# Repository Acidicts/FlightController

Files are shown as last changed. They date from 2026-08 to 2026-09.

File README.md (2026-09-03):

# My Simple Flight Controller
Made by following a tutorial by @notaroomba

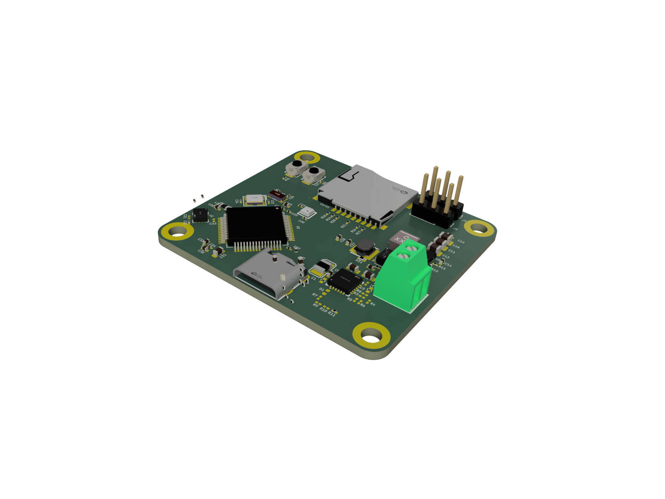
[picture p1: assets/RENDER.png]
RENDER IMG


<div style="display:inline-block">
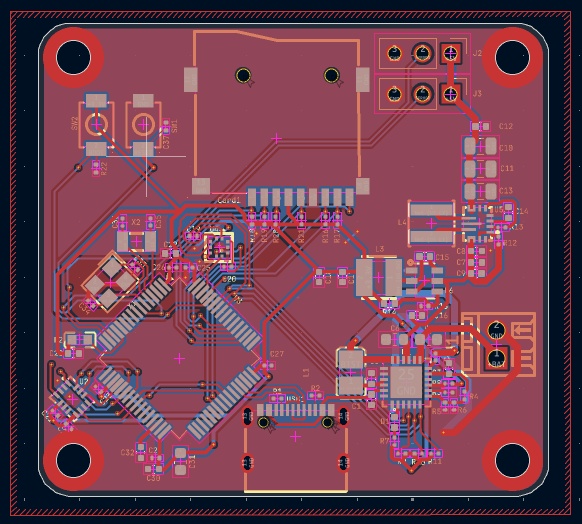
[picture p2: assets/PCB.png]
    
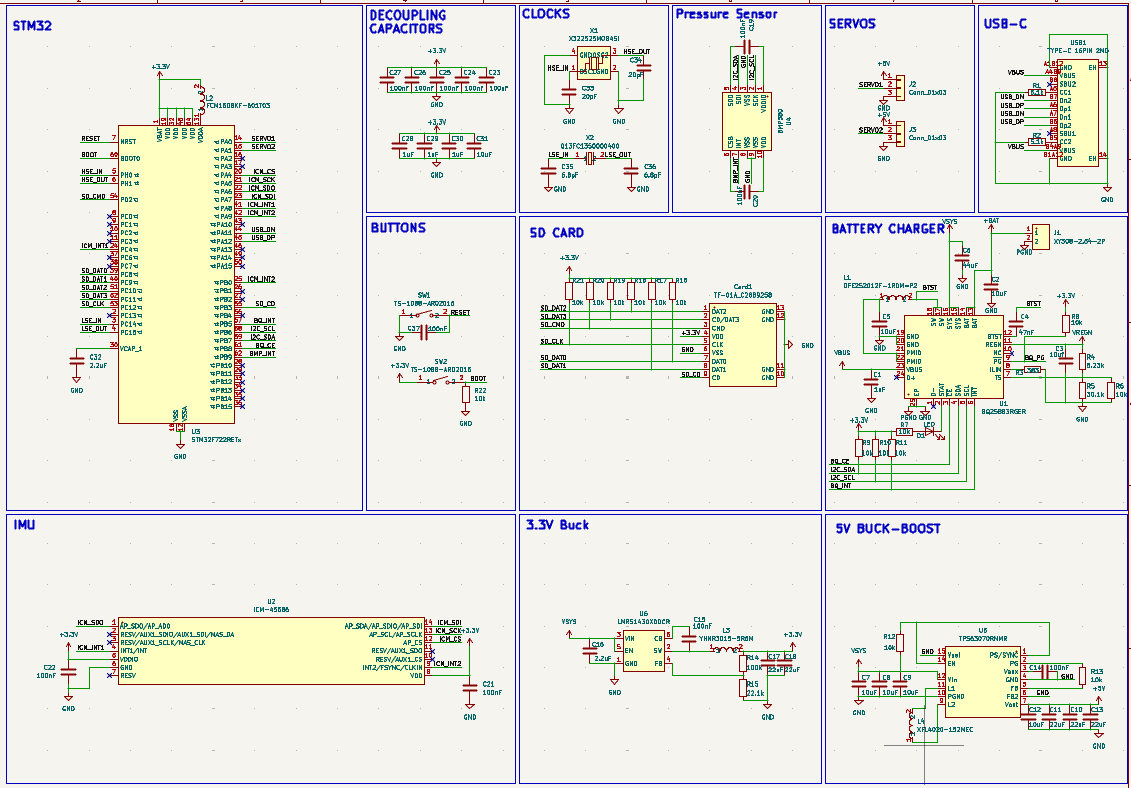
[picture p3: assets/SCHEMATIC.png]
    
</div>

## I learnt:
- That you can route sections of a pcb the bring them together to finish
- How to do ground fill in KiCAD
- That texas instruments is a good site to look on

## Features
| Name | Description | Part Name | Usage |
| --- | --- | --- | --- |
| MCU | High Speed MCU | STM32F722RET6 | This is the brains and allows management of all the other components connected to it |
| Barometer | For relative height measuring from launch altitude | BMP580 | This allows altitude tracking for each flight mission |
| IMU | Tracks movement | ICM-45686 | This allows tracking of the flight path and orientation of the craft using the 3 axis gyroscope in it |
| Battery Charger | Manages battery charging for Lithium Batteries | BQ25883RGER | This manages the battery and allows smooth discharge and charging of the battery to prevent damage to the battery and the board |
| High speed clock | Provides high-speed frequency to MCU (~25MHz) | X322525MOB4SI | This provides the main clock signal for the MCU |
| Low speed clock | Provides low-speed frequency to MCU (32.768kHz) | Q13FC13500004 | This provides a stable time base for the MCU |
| Battery Screw Terminal | For connecting battery | XY308-2.54-2P | This allows easy connection of the battery to the board (no soldering today) |
| Two servo pin headers | For connecting the servos | 2.54-1*3P | This allows easy connection of the servos to the board allowing hot swapping servos or cables |

## Getting Started
Click [here](GETTING_STARTED.md)

## BOM
[BOM](./BOM.csv)

[PCB BOM](./PCB_BOM.csv)

[PCB BOM UNSELECTED](./PCB_BOM_UNSELECTED.csv) - Most due to not being in stock or I couldn't find them on lcsc

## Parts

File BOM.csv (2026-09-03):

What | Quantity | Cost(USD) | Source
PCB | 5 | $4 | [jlcpcb.com](https://jlcpcb.com)
PCBA | 2 | $166+ | [jlcpcb.com](https://jlcpcb.com)
Shipping | X | $21.32 | [jlcpcb.com](https://jlcpcb.com)

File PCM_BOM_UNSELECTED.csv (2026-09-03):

Designator | Comment | Footprint | Reason | Qty | LCSC Part# | Name | Cost
R3 | 383 | 0201 | NOT IN STOCK | 2 | C423551 | 0201WMF3830TEE | $0.0005
C6 | 44uF | 0603 | Couldn't Find ON LCSC | 2

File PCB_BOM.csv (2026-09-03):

Part Name | Manufacturer/Type | Designator | Quantity | Supplier | Attrition Type | LCSC Part# | Unit Price | Source
TYPE-C 16PIN 2MD(073) | System | USB1 | 3 | JLCPCB | Extended | C2765186 | $0.2223 | [LCSC](https://www.lcsc.com/product-detail/C2765186.html)
XY308-2.54-2P | System | J1 | 2 | JLCPCB | Extended | C557685 | $0.4924 | [LCSC](https://www.lcsc.com/product-detail/C557685.html)
TS-1088-AR02016 | System | SW1,SW2 | 8 | JLCPCB | Basic | C720477 | $0.4448 | [LCSC](https://www.lcsc.com/product-detail/C720477.html)
GRM155R60J226ME11D | System | C17,C18 | 8 | JLCPCB | Extended | C415703 | $1.1928 | [LCSC](https://www.lcsc.com/product-detail/C415703.html)
CL21A226MAQNNNE | System | C10,C11,C13 | 6 | JLCPCB | Basic | C45783 | $2.1432 | [LCSC](https://www.lcsc.com/product-detail/C45783.html)
GRM0335C1H6R8CA01D | System | C35,C36 | 20 | JLCPCB | Extended | C85916 | $0.1540 | [LCSC](https://www.lcsc.com/product-detail/C85916.html)
CC0201KRX5R7BB473 | System | C4 | 20 | JLCPCB | Extended | C505465 | $0.1220 | [LCSC](https://www.lcsc.com/product-detail/C505465.html)
Q13FC13500004 | System | X2 | 5 | JLCPCB | Basic | C32346 | $0.8650 | [LCSC](https://www.lcsc.com/product-detail/C32346.html)
0201WMF5231TEE | Customer | R4 | 20 | JLCPCB | Extended | C423492 | $0.0300 | [LCSC](https://www.lcsc.com/product-detail/C423492.html)
TPS63070RNMR | System | U5 | 2 | JLCPCB | Extended | C109322 | $3.3682 | [LCSC](https://www.lcsc.com/product-detail/C109322.html)
DFE252012F-1R0M=P2 | System | L1 | 5 | JLCPCB | Extended | C435392 | $0.6150 | [LCSC](https://www.lcsc.com/product-detail/C435392.html)
CL05A225MQ5NSNC | System | C16,C32 | 20 | JLCPCB | Basic | C12530 | $0.1300 | [LCSC](https://www.lcsc.com/product-detail/C12530.html)
CL10A106KP8NNNC | System | C2,C31 | 20 | JLCPCB | Basic | C19702 | $0.7000 | [LCSC](https://www.lcsc.com/product-detail/C19702.html)
CC0201JRNPO9BN200 | System | C33,C34 | 20 | JLCPCB | Extended | C325444 | $0.0860 | [LCSC](https://www.lcsc.com/product-detail/C325444.html)
BMP580 | System | U4 | 2 | JLCPCB | Extended | C22391138 | $2.4068 | [LCSC](https://www.lcsc.com/product-detail/C22391138.html)
GRM033R61A104KE15D | System | C19,C20,C21,C22,C23,C24,C25,C26,C27,C37 | 32 | JLCPCB | Extended | C76934 | $0.2240 | [LCSC](https://www.lcsc.com/product-detail/C76934.html)
CL05A106MQ5NUNC | System | C12,C3,C5,C7,C8,C9 | 22 | JLCPCB | Basic | C15525 | $0.5610 | [LCSC](https://www.lcsc.com/product-detail/C15525.html)
X322525MOB4SI | System | X1 | 6 | JLCPCB | Basic | C9006 | $0.5664 | [LCSC](https://www.lcsc.com/product-detail/C9006.html)
CL05A105KA5NQNC | System | C1,C28,C29,C30 | 20 | JLCPCB | Basic | C52923 | $0.2420 | [LCSC](https://www.lcsc.com/product-detail/C52923.html)
TF-01A | System | CARD1 | 2 | JLCPCB | Extended | C2889258 | $0.1928 | [LCSC](https://www.lcsc.com/product-detail/C2889258.html)
CL05B104KO5NNNC | System | C14,C15 | 20 | JLCPCB | Basic | C1525 | $0.1100 | [LCSC](https://www.lcsc.com/product-detail/C1525.html)
STM32F722RET6 | Customer | U3 | 2 | JLCPCB | Extended | C118207 | $19.8390 | [LCSC](https://www.lcsc.com/product-detail/C118207.html)
FCM1608KF-601T03 | System | L2 | 20 | JLCPCB | Extended | C141723 | $0.2040 | [LCSC](https://www.lcsc.com/product-detail/C141723.html)
YHNR3015-5R6M | System | L3 | 15 | JLCPCB | Extended | C18236327 | $1.1310 | [LCSC](https://www.lcsc.com/product-detail/C18236327.html)
LMR51430XDDCR | System | U6 | 2 | JLCPCB | Extended | C5185863 | $1.8742 | [LCSC](https://www.lcsc.com/product-detail/C5185863.html)
XFL4020-152MEC | System | L4 | 2 | JLCPCB | Extended | C3033018 | $6.9574 | [LCSC](https://www.lcsc.com/product-detail/C3033018.html)
CR0201FH1002G | Customer | R10,R11,R12,R13,R16,R17,R18,R19,R20,R21,R22,R6,R7,R8,R9 | 42 | JLCPCB | Extended | C100126 | $0.1806 | [LCSC](https://www.lcsc.com/product-detail/C100126.html)
BQ25883RGER | System | U1 | 2 | JLCPCB | Extended | C544362 | $7.9512 | [LCSC](https://www.lcsc.com/product-detail/C544362.html)
ICM-45686 | System | U2 | 2 | JLCPCB | Extended | C22459454 | $23.6716 | [LCSC](https://www.lcsc.com/product-detail/C22459454.html)
2.54-1*3P | System | J2,J3 | 6 | JLCPCB | Extended | C49257 | $0.0556 | [LCSC](https://www.lcsc.com/product-detail/C49257.html)
RC0402FR-07100KL | System | R14 | 2 | JLCPCB | Basic | C60491 | $0.0088 | [LCSC](https://www.lcsc.com/product-detail/C60491.html)
YAGEO RT0201BRD075K1L | System | R1,R2 | 4 | JLCPCB | Extended | C852257 | $0.2424 | [LCSC](https://www.lcsc.com/product-detail/C852257.html)
VISHAY CRCW020130K1FKED | System | R5 | 2 | JLCPCB | Extended | C2087349 | $0.0028 | [LCSC](https://www.lcsc.com/product-detail/C2087349.html)
UNI-ROYAL 0201WMF2212TEE | System | R15 | 2 | JLCPCB | Extended | C423662 | $0.0030 | [LCSC](https://www.lcsc.com/product-detail/C423662.html)
CHONGTIAN CT-1005UBC-P4 | System | D1 | 2 | JLCPCB | Extended | C52675962 | $0.0132 | [LCSC](https://www.lcsc.com/product-detail/C52675962.html)

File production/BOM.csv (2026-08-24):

Designator | Footprint | Quantity | Value | LCSC Part #
C1, C28, C29, C30 | 0402 | 4 | 1uF
C10, C11, C13 | 0805 | 3 | 22uF
C12, C3, C5, C7, C8, C9 | 0402 | 6 | 10uF
C14, C15 | 0402 | 2 | 100nF
C16, C32 | 0402 | 2 | 2.2uF
C17, C18 | 0402 | 2 | 22uF
C19, C20, C21, C22, C23, C24, C25, C26, C27, C37 | 0201 | 10 | 100nF
C2, C31 | 0603 | 2 | 10uF
C33, C34 | 0201 | 2 | 20pF
C35, C36 | 0201 | 2 | 6.8pF
C4 | 0201 | 1 | 47nF
C6 | 0603 | 1 | 44uF
CARD1 | TF-SMD_TF-02 | 1 | TF-01A_C2889258 | C2889258
D1 | 0402 | 1 | LED
J1 | CONN-TH_XY308-2.54-2P | 1 | XY308-2.54-2P | C557685
J2, J3 | PinHeader_1x03_P2.54mm_Vertical | 2 | Conn_01x03
L1 | L2520 | 1 | DFE252012F-1R0M=P2 | C435392
L2 | L0603 | 1 | FCM1608KF-601T03 | C141723
L3 | IND-SMD_L3.0-W3.0 | 1 | YHNR3015-5R6M | C18236327
L4 | IND-SMD_L4.0-W4.0-A | 1 | XFL4020-152MEC | C3033018
R1, R2 | 0201 | 2 | 5.1k
R10, R11, R12, R13, R16, R17, R18, R19, R20, R21, R22, R6, R7, R8, R9 | 0201 | 15 | 10k
R14 | 0402 | 1 | 100k
R15 | 0201 | 1 | 22.1k
R3 | 0201 | 1 | 383
R4 | 0201 | 1 | 5.23k
R5 | 0201 | 1 | 30.1k
SW1, SW2 | SW-SMD_L3.9-W3.0-P4.45 | 2 | TS-1088-AR02016 | C720477
U1 | VFQFPN-24_L4.0-W4.0-P0.50-BL-EP2.8 | 1 | BQ25883RGER | C544362
U2 | LGA-14_L3.0-W2.5-P0.50-TL | 1 | ICM-45686 | C22459454
U3 | LQFP-64_10x10mm_P0.5mm | 1 | STM32F722RETx
U4 | LGA-10_L2.0-W2.0-P0.50-TL_BMP580 | 1 | BMP580 | C22391138
U5 | VQFN-15_L3.0-W2.5-P0.50-BL | 1 | TPS63070RNMR | C109322
U6 | SOT-23-6_L2.9-W1.6-P0.95-LS2.8-BL | 1 | LMR51430XDDCR | C5185863
USB1 | USB-C-SMD_TYPE-C-16PIN-2MD-073 | 1 | TYPE-C 16PIN 2MD | C2765186
X1 | CRYSTAL-SMD_4P-L3.2-W2.5-BL | 1 | X322525MOB4SI | C9006
X2 | FC-135R_L3.2-W1.5 | 1 | Q13FC1350000400 | C32346

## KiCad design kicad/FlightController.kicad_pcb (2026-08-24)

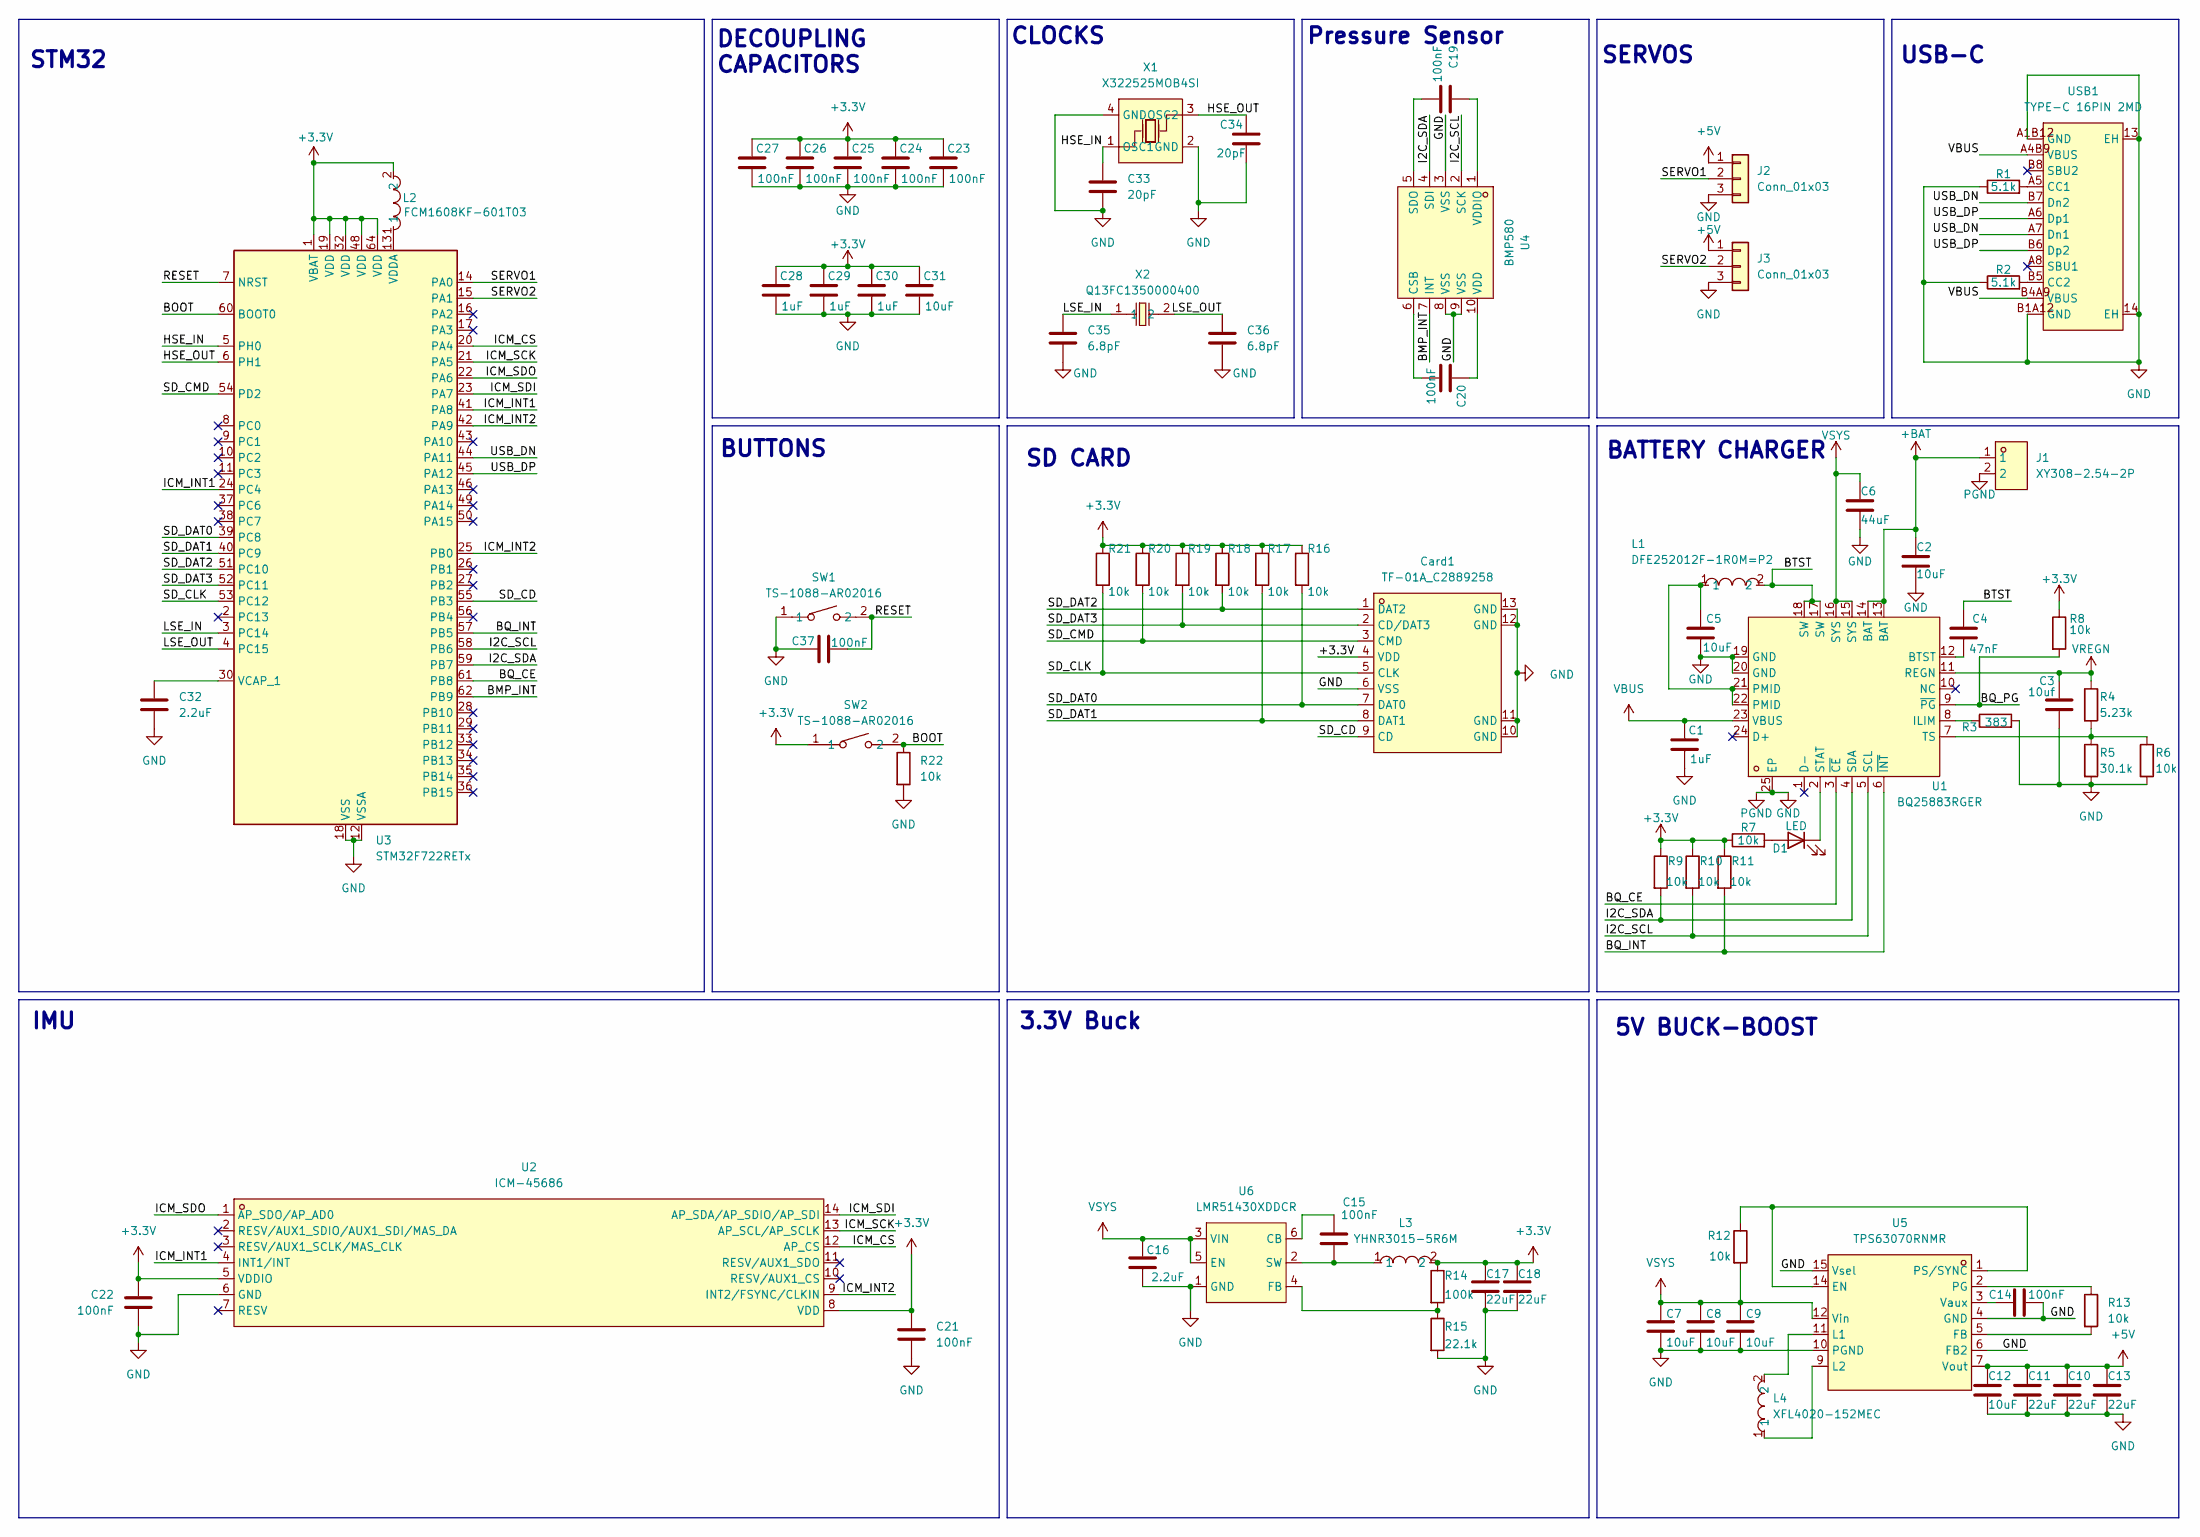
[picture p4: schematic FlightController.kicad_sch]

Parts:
C1, C28, C29, C30: 1uF; C_0402_1005Metric
C2, C31: 10uF; C_0603_1608Metric
C3: 10uf; C_0402_1005Metric
C4: 47nF; C_0201_0603Metric
C5, C7, C8, C9, C12: 10uF; C_0402_1005Metric
C6: 44uF; C_0603_1608Metric
C10, C11, C13: 22uF; C_0805_2012Metric
C14, C15: 100nF; C_0402_1005Metric
C16, C32: 2.2uF; C_0402_1005Metric
C17, C18: 22uF; C_0402_1005Metric
C19, C20, C21, C22, C23, C24, C25, C26, C27, C37: 100nF; C_0201_0603Metric
C33, C34: 20pF; C_0201_0603Metric
C35, C36: 6.8pF; C_0201_0603Metric
Card1: TF-01A_C2889258; TF-SMD_TF-02; MPN TF-01A; LCSC Part C2889258
D1: LED; LED_0402_1005Metric
J1: XY308-2.54-2P; CONN-TH_XY308-2.54-2P; MPN XY308-2.54-2P; LCSC Part C557685
J2, J3: Conn_01x03; PinHeader_1x03_P2.54mm_Vertical
L1: DFE252012F-1R0M=P2; L2520; MPN DFE252012F-1R0M=P2; LCSC Part C435392
L2: FCM1608KF-601T03; L0603; MPN FCM1608KF-601T03; LCSC Part C141723
L3: YHNR3015-5R6M; IND-SMD_L3.0-W3.0; MPN YHNR3015-5R6M; LCSC Part C18236327
L4: XFL4020-152MEC; IND-SMD_L4.0-W4.0-A; MPN XFL4020-152MEC; LCSC Part C3033018
R1, R2: 5.1k; R_0201_0603Metric
R3: 383; R_0201_0603Metric
R4: 5.23k; R_0201_0603Metric
R5: 30.1k; R_0201_0603Metric
R6, R7, R8, R9, R10, R11, R12, R13, R16, R17, R18, R19, R20, R21, R22: 10k; R_0201_0603Metric
R14: 100k; R_0402_1005Metric
R15: 22.1k; R_0201_0603Metric
SW1, SW2: TS-1088-AR02016; SW-SMD_L3.9-W3.0-P4.45; MPN TS-1088-AR02016; LCSC Part C720477
U1: BQ25883RGER; VFQFPN-24_L4.0-W4.0-P0.50-BL-EP2.8; MPN BQ25883RGER; LCSC Part C544362
U2: ICM-45686; LGA-14_L3.0-W2.5-P0.50-TL; MPN ICM-45686; LCSC Part C22459454
U3: STM32F722RETx; LQFP-64_10x10mm_P0.5mm
U4: BMP580; LGA-10_L2.0-W2.0-P0.50-TL_BMP580; MPN BMP580; LCSC Part C22391138
U5: TPS63070RNMR; VQFN-15_L3.0-W2.5-P0.50-BL; MPN TPS63070RNMR; LCSC Part C109322
U6: LMR51430XDDCR; SOT-23-6_L2.9-W1.6-P0.95-LS2.8-BL; MPN LMR51430XDDCR; LCSC Part C5185863
USB1: TYPE-C 16PIN 2MD; USB-C-SMD_TYPE-C-16PIN-2MD-073; MPN TYPE-C 16PIN 2MD(073); LCSC Part C2765186
X1: X322525MOB4SI; CRYSTAL-SMD_4P-L3.2-W2.5-BL; MPN X322525MOB4SI; LCSC Part C9006
X2: Q13FC1350000400; FC-135R_L3.2-W1.5; MPN Q13FC13500004; LCSC Part C32346

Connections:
+3.3V: C17.1, C18.1, C21.1, C22.1, C23.1, C24.1, C25.1, C26.1, C27.1, C28.1, C29.1, C30.1, C31.1, Card1.4 (VDD), L2.2, L3.2, R7.1, R8.1, R9.1, R10.1, R11.1, R14.1, R16.1, R17.1, R18.1, R19.1, R20.1, R21.1, SW2.1, U2.5 (VDDIO), U2.8 (VDD), U3.1 (VBAT), U3.19 (VDD), U3.32 (VDD), U3.48 (VDD), U3.64 (VDD)
+5V: C10.1, C11.1, C12.1, C13.1, J2.1, J3.1, U5.7 (Vout)
+BAT: C2.1, J1.1, U1.13 (BAT), U1.14 (BAT)
/BMP_INT: U3.62 (PB9), U4.7 (INT)
/BOOT: R22.1, SW2.2, U3.60 (BOOT0)
/BQ_CE: U1.3 (~CE), U3.61 (PB8)
/BQ_INT: R11.2, U1.6 (~INT), U3.57 (PB5)
/BQ_PG: R8.2, U1.9 (~PG)
/BTST: C4.1, L1.2, U1.17 (SW), U1.18 (SW)
/HSE_IN: C33.1, U3.5 (PH0), X1.1 (OSC1)
/HSE_OUT: C34.1, U3.6 (PH1), X1.3 (OSC2)
/I2C_SCL: R10.2, U1.5 (SCL), U3.58 (PB6), U4.2 (SCK)
/I2C_SDA: R9.2, U1.4 (SDA), U3.59 (PB7), U4.4 (SDI)
/ICM_CS: U2.12 (AP_CS), U3.20 (PA4)
/ICM_INT1: U2.4 (INT1/INT), U3.24 (PC4), U3.41 (PA8)
/ICM_INT2: U2.9 (INT2/FSYNC/CLKIN), U3.25 (PB0), U3.42 (PA9)
/ICM_SCK: U2.13 (AP_SCL/AP_SCLK), U3.21 (PA5)
/ICM_SDI: U2.14 (AP_SDA/AP_SDIO/AP_SDI), U3.23 (PA7)
/ICM_SDO: U2.1 (AP_SDO/AP_AD0), U3.22 (PA6)
/LSE_IN: C35.1, U3.3 (PC14), X2.1
/LSE_OUT: C36.1, U3.4 (PC15), X2.2
/RESET: C37.2, SW1.2, U3.7 (NRST)
/SD_CD: Card1.9 (CD), U3.55 (PB3)
/SD_CLK: Card1.5 (CLK), R21.2, U3.53 (PC12)
/SD_CMD: Card1.3 (CMD), R20.2, U3.54 (PD2)
/SD_DAT0: Card1.7 (DAT0), R16.2, U3.39 (PC8)
/SD_DAT1: Card1.8 (DAT1), R17.2, U3.40 (PC9)
/SD_DAT2: Card1.1 (DAT2), R18.2, U3.51 (PC10)
/SD_DAT3: Card1.2 (CD/DAT3), R19.2, U3.52 (PC11)
/SERVO1: J2.2, U3.14 (PA0)
/SERVO2: J3.2, U3.15 (PA1)
/USB_DN: U3.44 (PA11), USB1.A7 (Dn1), USB1.B7 (Dn2)
/USB_DP: U3.45 (PA12), USB1.A6 (Dp1), USB1.B6 (Dp2)
GND: C1.2, C2.2, C3.2, C5.2, C6.2, C7.2, C8.2, C9.2, C10.2, C11.2, C12.2, C13.2, C14.2, C16.2, C17.2, C18.2, C21.2, C22.2, C23.2, C24.2, C25.2, C26.2, C27.2, C28.2, C29.2, C30.2, C31.2, C32.2, C33.2, C34.2, C35.2, C36.2, C37.1, Card1.6 (VSS), Card1.10 (GND), Card1.11 (GND), Card1.12 (GND), Card1.13 (GND), J1.2, J2.3, J3.3, R1.1, R2.1, R3.2, R5.2, R6.2, R15.2, R22.2, SW1.1, U1.19 (GND), U1.20 (GND), U1.25 (EP), U2.6 (GND), U3.12 (VSSA), U3.18 (VSS), U3.31 (VSS), U3.47 (VSS), U3.63 (VSS), U4.3 (VSS), U4.8 (VSS), U4.9 (VSS), U5.4 (GND), U5.6 (FB2), U5.10 (PGND), U5.15 (Vsel), U6.1 (GND), USB1.13 (EH), USB1.14 (EH), USB1.A1B12 (GND), USB1.B1A12 (GND), X1.2 (GND), X1.4 (GND)
unnamed: C5.1, L1.1, U1.21 (PMID), U1.22 (PMID)
unnamed: D1.2 (A), R7.2
unnamed: D1.1 (K), U1.2 (STAT)
unnamed: C4.2, U1.12 (BTST)
unnamed: R3.1, U1.8 (ILIM)
unnamed: R4.2, R5.1, R6.1, U1.7 (TS)
unnamed: C32.1, U3.30 (VCAP_1)
unnamed: L2.1, U3.13 (VDDA)
unnamed: C20.2, U4.6 (CSB)
unnamed: C19.2, U4.5 (SDO)
unnamed: C20.1, U4.10 (VDD)
unnamed: C19.1, U4.1 (VDDIO)
unnamed: R12.1, U5.1 (PS/SYNC), U5.14 (EN)
unnamed: R13.2, U5.5 (FB)
unnamed: L4.2, U5.11 (L1)
unnamed: L4.1, U5.9 (L2)
unnamed: R13.1, U5.2 (PG)
unnamed: C14.1, U5.3 (Vaux)
unnamed: C15.1, U6.6 (CB)
unnamed: R14.2, R15.1, U6.4 (FB)
unnamed: C15.2, L3.1, U6.2 (SW)
unnamed: R1.2, USB1.A5 (CC1)
unnamed: R2.2, USB1.B5 (CC2)
VBUS: C1.1, U1.23 (VBUS), USB1.A4B9 (VBUS), USB1.B4A9 (VBUS)
VREGN: C3.1, R4.1, U1.11 (REGN)
VSYS: C6.1, C7.1, C8.1, C9.1, C16.1, R12.2, U1.15 (SYS), U1.16 (SYS), U5.12 (Vin), U6.3 (VIN), U6.5 (EN)

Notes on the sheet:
BUTTONS
SERVOS
IMU
CLOCKS
SD CARD
5V BUCK-BOOST
DECOUPLING CAPACITORS
STM32
BATTERY CHARGER
Pressure Sensor
USB-C
3.3V Buck

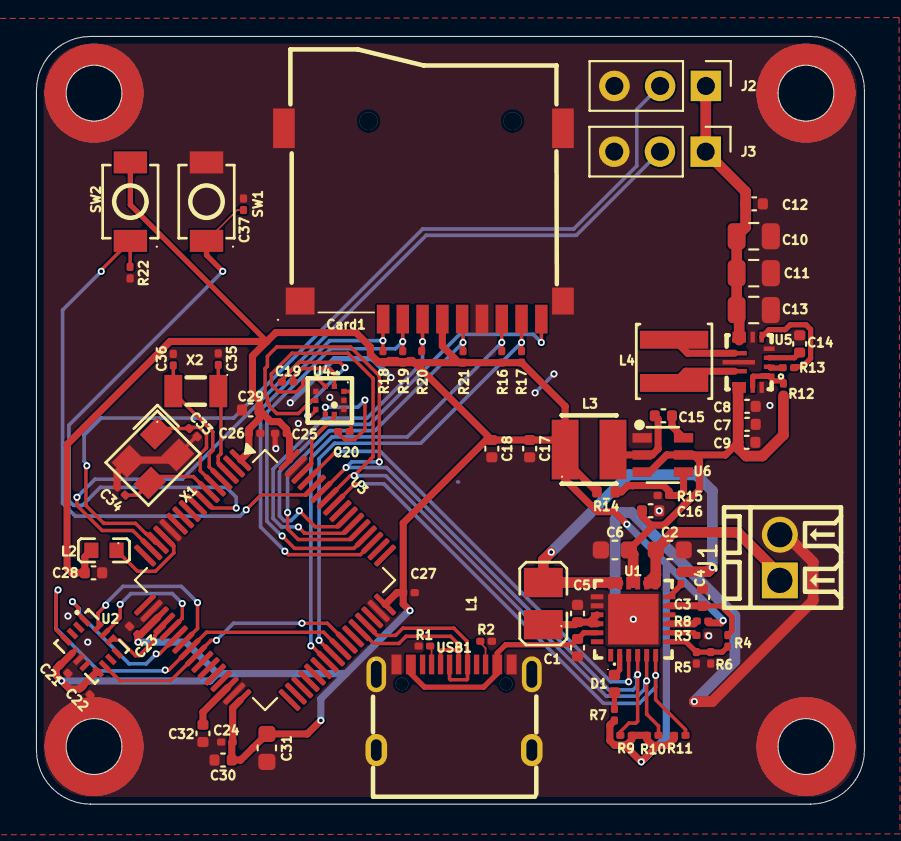
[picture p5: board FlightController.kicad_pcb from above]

Board: 2 copper layers, 46.0 x 42.6 mm, 79 parts (0 on the bottom side), 60 nets.

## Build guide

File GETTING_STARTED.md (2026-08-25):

# Getting Started
** Should be PCBA due to small parts **

## Step 1: Modify the firmware to meet your needs
- Add and edit code within `/* USER CODE BEGIN Includes */` and `/* USER CODE END Includes */` in [`software/Core/Src/main.c`](software/Core/Src/main.c)

## Step 2: Install and Build with Make
- Click [here](MAKE.md)

## Step 3: Install the firmware
- Use STM32CubeProgrammer over ST-Link/SWD to flash `FlightController.bin`, from your build folder after using make, at address 0x08000000
- Hold BOOT button while powering it on

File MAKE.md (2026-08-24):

# Make — Quickstart (Just the Steps)

## 1. Install

**Windows**
```
choco install make
```
(no choco? install it from https://chocolatey.org/install, then run the command above)

Or via winget:
```
winget install GnuWin32.Make
```

**macOS**
```
xcode-select --install
```
(installs make along with dev tools)

Or via Homebrew:
```
brew install make
```

**Linux (Debian/Ubuntu)**
```
sudo apt update && sudo apt install make
```

**Linux (Fedora/RHEL)**
```
sudo dnf install make
```

## 2. Check it's installed
```
make --version
```
If you see a version number, you're done with setup.

## 3. Running Make

**Run make in your software/ folder:**
```
make
```

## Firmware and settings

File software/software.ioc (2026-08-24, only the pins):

Mcu.UserName=STM32F722RETx
PA0-WKUP.Signal=S_TIM2_CH1_ETR
PA1.Signal=S_TIM2_CH2
PA11.Signal=USB_OTG_FS_DM
PA12.Signal=USB_OTG_FS_DP
PA4.Signal=SPI1_NSS
PA5.Signal=SPI1_SCK
PA6.Signal=SPI1_MISO
PA7.Signal=SPI1_MOSI
PB0.GPIO_Label=ICM_INT2
PB0.Signal=GPXTI0
PB3.GPIO_Label=SD_CS
PB3.Signal=GPIO_Input
PB5.GPIO_Label=BQ_INT
PB5.Signal=GPXTI5
PB6.Signal=I2C1_SCL
PB7.Signal=I2C1_SDA
PB8.GPIO_Label=BQ_CE
PB8.Signal=GPIO_Output
PB9.GPIO_Label=BMP_INT
PB9.Signal=GPXTI9
PC10.Signal=SDMMC1_D2
PC11.Signal=SDMMC1_D3
PC12.Signal=SDMMC1_CK
PC14-OSC32_IN.Signal=RCC_OSC32_IN
PC15-OSC32_OUT.Signal=RCC_OSC32_OUT
PC4.GPIO_Label=ICM_INT1
PC4.Signal=GPXTI4
PC8.Signal=SDMMC1_D0
PC9.Signal=SDMMC1_D1
PD2.Signal=SDMMC1_CMD
PH0-OSC_IN.Signal=RCC_OSC_IN
PH1-OSC_OUT.Signal=RCC_OSC_OUT

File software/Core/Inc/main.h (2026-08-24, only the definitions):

#define ICM_INT1_Pin GPIO_PIN_4
#define ICM_INT1_GPIO_Port GPIOC
#define ICM_INT2_Pin GPIO_PIN_0
#define ICM_INT2_GPIO_Port GPIOB
#define SD_CS_Pin GPIO_PIN_3
#define SD_CS_GPIO_Port GPIOB
#define BQ_INT_Pin GPIO_PIN_5
#define BQ_INT_GPIO_Port GPIOB
#define BQ_CE_Pin GPIO_PIN_8
#define BQ_CE_GPIO_Port GPIOB
#define BMP_INT_Pin GPIO_PIN_9
#define BMP_INT_GPIO_Port GPIOB

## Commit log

2026-08-24 Upload of repo files
    [BOM.csv, FlightController.kicad_pcb, FlightController.kicad_sch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]
2026-08-25 Update GETTING_STARTED.md with PCBA note
    Added note about PCBA due to small parts.
2026-09-03 Improve README and add PCB Components bom with price [slack thread](https://hackclub.slack.com/archives/C0AV7EAB9K7/p1787884638530039)
    [PCB_BOM.csv, PCM_BOM_UNSELECTED.csv]
2026-09-03 Update hyperlinks
    [BOM.csv, PCB_BOM.csv]

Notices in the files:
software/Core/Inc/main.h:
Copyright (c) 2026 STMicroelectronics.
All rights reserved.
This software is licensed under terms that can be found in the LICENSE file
